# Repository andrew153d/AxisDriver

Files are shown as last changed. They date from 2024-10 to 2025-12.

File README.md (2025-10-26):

# AxisDriver Project

## Overview
The AxisDriver project is a comprehensive solution for controlling motorized devices, designed for robotics and automation applications. It integrates firmware, software, and hardware components to provide a robust and flexible platform for motor control and peripheral management.

## Directory Structure
- `firmware/`: Firmware source code, libraries, and PlatformIO configuration.
- `examples/Python/`: Python scripts for hardware interfacing and control.
- `hardware/`: KiCad files for PCB designs, including Ethernet HATs and mainboards.
- `test/`: Unit tests for hardware components.
- `scripts/`: Utility scripts for generating interfaces and managing configurations.

## Getting Started

### Building the Firmware
1. Navigate to the `firmware/` directory.
2. Build the firmware using PlatformIO:
   ```bash
   platformio run
   ```

### Running Python Scripts
- There are a few python scripts that can control motors over ethernet or USB
1. Navigate to the `examples/Python/` directory.
2. Run the desired script using Python:
   ```bash
   python3 <script_name>.py
   ```

### Ethernet Debugging
- If DEBUG_UDP is defined, run the following in a linux terminal to see messages
```
nc -u -lk 35461
```

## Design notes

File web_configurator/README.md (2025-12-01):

# Axis Driver Web Configurator

A retro computing-themed web interface for configuring and controlling the Axis Driver motor control system.

## 🚀 Quick Start

### Method 1: Use the startup script (Recommended)
```bash
cd web_configurator
./start_server.sh
```

### Method 2: Run Python server directly
```bash
cd web_configurator
python3 serve.py
```

### Method 3: Use any HTTP server
```bash
cd web_configurator
# Python built-in server
python3 -m http.server 8000

# Or Node.js if you have it
npx http-server -p 8000

# Or PHP if you have it
php -S localhost:8000
```

## 🌐 Accessing the Interface

1. Start the server using one of the methods above
2. Open your web browser to: **http://localhost:8000**
3. Connect your Axis Driver via USB
4. Click **[ESTABLISH LINK]** to connect

## ⚡ Requirements

- **Browser**: Chrome 89+ or Edge 89+ (Web Serial API support)
- **Connection**: USB cable to Axis Driver
- **Server**: Python 3 (or any HTTP server)

## 🔧 Features

- **Device Connection**: Serial communication with Axis Driver
- **System Configuration**: Firmware version, I2C, Ethernet settings
- **LED Control**: RGB color and animation control
- **Home Calibration**: Motor homing and calibration
- **Motor Control**: Position, velocity, and path control

## 🎨 Interface

The interface features a retro computing terminal aesthetic with:
- Green-on-black terminal color scheme
- CRT monitor effects (scan lines, flicker)
- Command-line style controls
- Real-time status monitoring
- Monospace terminal font

## 🔐 Security Notes

- The Web Serial API requires either HTTPS or localhost
- Make sure you trust the device you're connecting to
- Only connect genuine Axis Driver devices

## 🐛 Troubleshooting

### "Web Serial API not supported"
- Use Chrome 89+ or Edge 89+
- Ensure you're accessing via HTTP/HTTPS (not file://)

### "HTTPS Required"
- Use localhost instead of file:// protocol
- Serve the files via HTTP server (see instructions above)

### "No Port Selected" 
- Make sure Axis Driver is connected via USB
- Check that device drivers are installed
- Try a different USB cable/port

### "Port Busy"
- Close other applications that might be using the serial port
- Disconnect and reconnect the device
- Refresh the browser page

## 📁 Files

- `index.html` - Main interface
- `style.css` - Retro terminal styling
- `script.js` - Connection and control logic
- `AxisProtocol.js` - Protocol implementation
- `serve.py` - Python HTTP server
- `start_server.sh` - Quick start script

## 🎯 Usage

1. **Connect**: Click [ESTABLISH LINK] to connect via USB
2. **Configure**: Set device parameters (I2C, Ethernet, etc.)
3. **Control**: Use motor control commands
4. **Monitor**: View real-time status and feedback
5. **Disconnect**: Click [DISCONNECT] when done

The interface provides full control over the Axis Driver's configuration and motor control capabilities in an immersive retro computing environment.

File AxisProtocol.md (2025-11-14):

# Axis Driver Protocol Documentation

This document describes the communication protocol for the Axis Driver firmware (Version 1.0.0.0).

## Protocol Overview

The protocol uses a structured message format with a header, body, and footer. All messages are packed structures without padding.

### Message Structure

All messages follow this basic structure:
- **Header** (4 bytes): Message type (2 bytes) + Body size (2 bytes)
- **Body** (variable): Message-specific data
- **Footer** (2 bytes): Checksum

### Data Types

- `uint8_t`: 1 byte unsigned integer
- `int8_t`: 1 byte signed integer
- `uint16_t`: 2 bytes unsigned integer
- `uint32_t`: 4 bytes unsigned integer
- `int32_t`: 4 bytes signed integer
- `double`: 8 bytes floating point

## Message Types

### 0x0100 - ACK (AckId)

**Description**: Acknowledgment message for successful command reception and execution.

| Byte Offset | Size | Field | Description |
| --- | ---- | --- | --- |
| 0-1 | 2 | message_type | 0x0100 |
| 2-3 | 2 | body_size | 3 |
| 4-5 | 2 | ack_message_type | Message type being acknowledged |
| 6 | 1 | status | Status code (0=SUCCESS, 1=ERROR, 2=INVALID_COMMAND) |
| 7-8 | 2 | checksum | Message checksum |

**Status Codes:**
- 0x0: SUCCESS - Command executed successfully
- 0x1: ERROR - Command failed during execution
- 0x2: INVALID_COMMAND - Unknown or malformed command

### 0x0101 - Get Version (GetVersionId)

**Description**: Request firmware version information.

| Byte Offset | Size | Field | Description |
| --- | ---- | --- | --- |
| 0-1 | 2 | message_type | 0x0101 |
| 2-3 | 2 | body_size | 4 |
| 4-7 | 4 | version | Firmware version as uint32_t |
| 8-9 | 2 | checksum | Message checksum |

### 0x0102 - Set I2C Address (SetI2CAddressId)

**Description**: Set the I2C address for the device.

| Byte Offset | Size | Field | Description |
| --- | ---- | --- | --- |
| 0-1 | 2 | message_type | 0x0102 |
| 2-3 | 2 | body_size | 1 |
| 4 | 1 | address | I2C address (0-127) |
| 5-6 | 2 | checksum | Message checksum |

### 0x0103 - Get I2C Address (GetI2CAddressId)

**Description**: Request current I2C address.

| Byte Offset | Size | Field | Description |
| --- | ---- | --- | --- |
| 0-1 | 2 | message_type | 0x0103 |
| 2-3 | 2 | body_size | 1 |
| 4 | 1 | address | Current I2C address |
| 5-6 | 2 | checksum | Message checksum |

### 0x0104 - Set Ethernet Address (SetEthernetAddressId)

**Description**: Set the Ethernet IP address for the device.

| Byte Offset | Size | Field | Description |
| --- | ---- | --- | --- |
| 0-1 | 2 | message_type | 0x0104 |
| 2-3 | 2 | body_size | 4 |
| 4-7 | 4 | ip_address | IP address as uint32_t |
| 8-9 | 2 | checksum | Message checksum |

### 0x0105 - Get Ethernet Address (GetEthernetAddressId)

**Description**: Request current Ethernet IP address.

| Byte Offset | Size | Field | Description |
| --- | ---- | --- | --- |
| 0-1 | 2 | message_type | 0x0105 |
| 2-3 | 2 | body_size | 4 |
| 4-7 | 4 | ip_address | Current IP address as uint32_t |
| 8-9 | 2 | checksum | Message checksum |

### 0x0106 - Set Ethernet Port (SetEthernetPortId)

**Description**: Set the Ethernet port number for the device.

| Byte Offset | Size | Field | Description |
| --- | ---- | --- | --- |
| 0-1 | 2 | message_type | 0x0106 |
| 2-3 | 2 | body_size | 4 |
| 4-7 | 4 | port | Port number as uint32_t |
| 8-9 | 2 | checksum | Message checksum |

### 0x0107 - Get Ethernet Port (GetEthernetPortId)

**Description**: Request current Ethernet port number.

| Byte Offset | Size | Field | Description |
| --- | ---- | --- | --- |
| 0-1 | 2 | message_type | 0x0107 |
| 2-3 | 2 | body_size | 4 |
| 4-7 | 4 | port | Current port number as uint32_t |
| 8-9 | 2 | checksum | Message checksum |

### 0x0108 - Get MAC Address (GetMacAddressId)

**Description**: Request device MAC address.

| Byte Offset | Size | Field | Description |
| --- | ---- | --- | --- |
| 0-1 | 2 | message_type | 0x0108 |
| 2-3 | 2 | body_size | 6 |
| 4-9 | 6 | mac_address  | MAC address bytes |
| 10-11 | 2 | checksum | Message checksum  |

### 0x0109 - Save Configuration (SaveConfigurationId)

**Description**: Save current configuration to non-volatile memory.

| Byte Offset | Size | Field | Description |
| --- | ---- | --- | --- |
| 0-1 | 2 | message_type | 0x0109 |
| 2-3 | 2 | body_size | 1 |
| 4 | 1 | save_flag | 1 to save, 0 for no action |
| 5-6 | 2 | checksum | Message checksum |

### 0x0200 - Set LED Color (SetLedColorId)

**Description**: Set the LED color (RGB values).

| Byte Offset | Size | Field | Description |
| --- | ---- | --- | --- |
| 0-1 | 2 | message_type | 0x0200 |
| 2-3 | 2 | body_size | 3 |
| 4 | 1 | red | Red component (0-255) |
| 5 | 1 | green | Green component (0-255) |
| 6 | 1 | blue | Blue component (0-255)  |
| 7-8 | 2 | checksum | Message checksum |

### 0x0201 - Get LED Color (GetLedColorId)

**Description**: Request current LED color.

| Byte Offset | Size | Field | Description |
| --- | ---- | --- | --- |
| 0-1 | 2 | message_type | 0x0201 |
| 2-3 | 2 | body_size | 3 |
| 4 | 1 | red | Current red component |
| 5 | 1 | green | Current green component |
| 6 | 1 | blue | Current blue component  |
| 7-8 | 2 | checksum | Message checksum |

### 0x0202 - Add Led Step (AddLedStepId)

**Description**: Add a timed LED step with a duration and color. Useful for sequencing LED patterns step-by-step.

| Byte Offset | Size | Field | Description |
| --- | ---- | --- | --- |
| 0-1 | 2 | message_type | 0x0202 |
| 2-3 | 2 | body_size | 7 |
| 4-7 | 4 | time_ms | Duration/time in milliseconds (uint32_t) |
| 8 | 1 | red | Red component (0-255) |
| 9 | 1 | green | Green component (0-255) |
| 10 | 1 | blue | Blue component (0-255) |
| 11-12 | 2 | checksum | Message checksum |

### 0x0300 - Set Home Direction (SetHomeDirectionId)

**Description**: Set the homing direction for the motor.

| Byte Offset | Size | Field | Description |
| --- | ---- | --- | --- |
| 0-1 | 2 | message_type | 0x0300 |
| 2-3 | 2 | body_size | 1 |
| 4 | 1 | direction | Home direction (0=CLOCKWISE, 1=COUNTERCLOCKWISE) |
| 5-6 | 2 | checksum | Message checksum |

### 0x0301 - Get Home Direction (GetHomeDirectionId)

**Description**: Request current homing direction.

| Byte Offset | Size | Field | Description |
| --- | ---- | --- | --- |
| 0-1 | 2 | message_type | 0x0301 |
| 2-3 | 2 | body_size | 1 |
| 4 | 1 | direction | Current home direction |
| 5-6 | 2 | checksum | Message checksum |

### 0x0302 - Set Home Threshold (SetHomeThresholdId)

**Description**: Set the threshold value for homing detection.

| Byte Offset | Size | Field | Description |
| --- | ---- | --- | --- |
| 0-1 | 2 | message_type | 0x0302 |
| 2-3 | 2 | body_size | 4 |
| 4-7 | 4 | threshold | Home detection threshold as uint32_t |
| 8-9 | 2 | checksum | Message checksum |

### 0x0303 - Get Home Threshold (GetHomeThresholdId)

**Description**: Request current home threshold value.

| Byte Offset | Size | Field | Description |
| --- | ---- | --- | --- |
| 0-1 | 2 | message_type | 0x0303 |
| 2-3 | 2 | body_size | 4 |
| 4-7 | 4 | threshold | Current home threshold |
| 8-9 | 2 | checksum | Message checksum |

### 0x0304 - Set Home Speed (SetHomeSpeedId)

**Description**: Set the speed for homing operations.

| Byte Offset | Size | Field | Description |
| --- | ---- | --- | --- |
| 0-1 | 2 | message_type | 0x0304 |
| 2-3 | 2 | body_size | 4 |
| 4-7 | 4 | speed | Home speed as uint32_t |
| 8-9 | 2 | checksum | Message checksum |

### 0x0305 - Get Home Speed (GetHomeSpeedId)

**Description**: Request current homing speed.

| Byte Offset | Size | Field | Description |
| --- | ---- | --- | --- |
| 0-1 | 2 | message_type | 0x0305 |
| 2-3 | 2 | body_size | 4 |
| 4-7 | 4 | speed | Current home speed |
| 8-9 | 2 | checksum | Message checksum |

### 0x0306 - Get Homed State (GetHomedStateId)

**Description**: Request whether the motor has been homed.

| Byte Offset | Size | Field | Description |
| --- | ---- | --- | --- |
| 0-1 | 2 | message_type | 0x0306 |
| 2-3 | 2 | body_size | 1 |
| 4 | 1 | homed | 1 if homed, 0 if not homed |
| 5-6 | 2 | checksum | Message checksum |

### 0x0400 - Home (HomeId)

**Description**: Initiate homing sequence.

| Byte Offset | Size | Field | Description |
| --- | ---- | --- | --- |
| 0-1 | 2 | message_type | 0x0400 |
| 2-3 | 2 | body_size | 4 |
| 4-7 | 4 | home_command | Home command value |
| 8-9 | 2 | checksum | Message checksum |

### 0x0307 - Set Motor State (SetMotorStateId)

**Description**: Set the motor control state/mode.

| Byte Offset | Size | Field | Description |
| --- | ---- | --- | --- |
| 0-1 | 2 | message_type | 0x0307 |
| 2-3 | 2 | body_size | 1 |
| 4 | 1 | motor_state  | Motor state (see MotorStates enum) |
| 5-6 | 2 | checksum | Message checksum |

**Motor States:**
- 0x0: OFF
- 0x1: POSITION
- 0x2: VELOCITY
- 0x3: VELOCITY_STEP
- 0x4: IDLE_ON
- 0x5: HOME

### 0x0308 - Get Motor State (GetMotorStateId)

**Description**: Request current motor state.

| Byte Offset | Size | Field | Description |
| --- | ---- | --- | --- |
| 0-1 | 2 | message_type | 0x0308 |
| 2-3 | 2 | body_size | 1 |
| 4 | 1 | motor_state  | Current motor state |
| 5-6 | 2 | checksum | Message checksum |

### 0x0309 - Set Motor Brake (SetMotorBrakeId)

**Description**: Set the motor braking mode.

| Byte Offset | Size | Field | Description |
| --- | ---- | --- | --- |
| 0-1 | 2 | message_type | 0x0309 |
| 2-3 | 2 | body_size | 1 |
| 4 | 1 | brake_mode | Brake mode (see MotorBrake enum) |
| 5-6 | 2 | checksum | Message checksum |

**Motor Brake Modes:**
- 0x0: NORMAL
- 0x1: FREEWHEELING
- 0x2: STRONG_BRAKING
- 0x3: BRAKING

### 0x030A - Get Motor Brake (GetMotorBrakeId)

**Description**: Request current motor brake mode.

| Byte Offset | Size | Field | Description |
| --- | ---- | --- | --- |
| 0-1 | 2 | message_type | 0x030A |
| 2-3 | 2 | body_size | 1 |
| 4 | 1 | brake_mode | Current brake mode |
| 5-6 | 2 | checksum | Message checksum |

### 0x030B - Set Max Speed (SetMaxSpeedId)

**Description**: Set the maximum motor speed.

| Byte Offset | Size | Field | Description |
| --- | ---- | --- | --- |
| 0-1 | 2 | message_type | 0x030B |
| 2-3 | 2 | body_size | 4 |
| 4-7 | 4 | max_speed | Maximum speed as uint32_t |
| 8-9 | 2 | checksum | Message checksum |

### 0x030C - Get Max Speed (GetMaxSpeedId)

**Description**: Request current maximum speed setting.

| Byte Offset | Size | Field | Description |
| --- | ---- | --- | --- |
| 0-1 | 2 | message_type | 0x030C |
| 2-3 | 2 | body_size | 4 |
| 4-7 | 4 | max_speed | Current maximum speed |
| 8-9 | 2 | checksum | Message checksum |

### 0x030D - Set Acceleration (SetAccelerationId)

**Description**: Set the motor acceleration value.

| Byte Offset | Size | Field | Description |
| --- | ---- | --- | --- |
| 0-1 | 2 | message_type | 0x030D |
| 2-3 | 2 | body_size | 4 |
| 4-7 | 4 | acceleration | Acceleration as uint32_t |
| 8-9 | 2 | checksum | Message checksum |

### 0x030E - Get Acceleration (GetAccelerationId)

**Description**: Request current acceleration setting.

| Byte Offset | Size | Field | Description |
| --- | ---- | --- | --- |
| 0-1 | 2 | message_type | 0x030E |
| 2-3 | 2 | body_size | 4 |
| 4-7 | 4 | acceleration | Current acceleration |
| 8-9 | 2 | checksum | Message checksum |

### 0x030F - Set Current Position (SetCurrentPositionId)

**Description**: Set the current position (zero/reference the position).

| Byte Offset | Size | Field | Description |
| --- | ---- | --- | --- |
| 0-1 | 2 | message_type | 0x030F |
| 2-3 | 2 | body_size | 8 |
| 4-11 | 8 | position | Position in degrees as double |
| 12-13 | 2 | checksum | Message checksum |

### 0x0310 - Get Current Position (GetCurrentPositionId)

**Description**: Request current motor position.

| Byte Offset | Size | Field | Description |
| --- | ---- | --- | --- |
| 0-1 | 2 | message_type | 0x0310 |
| 2-3 | 2 | body_size | 8 |
| 4-11 | 8 | position | Current position in degrees as double |
| 12-13 | 2 | checksum | Message checksum |

### 0x0311 - Set Target Position (SetTargetPositionId)

**Description**: Set the target position for position control mode.

| Byte Offset | Size | Field | Description |
| --- | ---- | --- | --- |
| 0-1 | 2 | message_type | 0x0311 |
| 2-3 | 2 | body_size | 8 |
| 4-11 | 8 | position | Target position in degrees as double |
| 12-13 | 2 | checksum | Message checksum |

### 0x0312 - Get Target Position (GetTargetPositionId)

**Description**: Request current target position.

| Byte Offset | Size | Field | Description |
| --- | ---- | --- | --- |
| 0-1 | 2 | message_type | 0x0312 |
| 2-3 | 2 | body_size | 8 |
| 4-11 | 8 | position | Current target position in degrees as double |
| 12-13 | 2 | checksum | Message checksum |

### 0x0401 - Set Relative Target Position (SetRelativeTargetPositionId)

**Description**: Set a target position relative to the current position.

| Byte Offset | Size | Field | Description |
| --- | ---- | --- | --- |
| 0-1 | 2 | message_type | 0x0401 |
| 2-3 | 2 | body_size | 8 |
| 4-11 | 8 | relative_position | Relative position in degrees as double |
| 12-13 | 2 | checksum | Message checksum |

### 0x0313 - Set Velocity (SetVelocityId)

**Description**: Set the motor velocity for velocity control mode.

| Byte Offset | Size | Field | Description |
| --- | ---- | --- | --- |
| 0-1 | 2 | message_type | 0x0313 |
| 2-3 | 2 | body_size | 8 |
| 4-11 | 8 | velocity | Velocity in degrees/second as double |
| 12-13 | 2 | checksum | Message checksum |

### 0x0314 - Get Velocity (GetVelocityId)

**Description**: Request current motor velocity.

| Byte Offset | Size | Field | Description |
| --- | ---- | --- | --- |
| 0-1 | 2 | message_type | 0x0314 |
| 2-3 | 2 | body_size | 8 |
| 4-11 | 8 | velocity | Current velocity in degrees/second as double |
| 12-13 | 2 | checksum | Message checksum |

### 0x0402 - Set Velocity and Steps (SetVelocityAndStepsId)

**Description**: Set velocity and number of steps with position mode.

| Byte Offset | Size | Field | Description |
| --- | ---- | --- | --- |
| 0-1 | 2 | message_type  | 0x0402 |
| 2-3 | 2 | body_size | 9 |
| 4-7 | 4 | velocity | Velocity as int32_t |
| 8-11 | 4 | steps | Number of steps as int32_t |
| 12 | 1 | position_mode | Position mode (0=ABSOLUTE, 1=RELATIVE) |
| 13-14 | 2 | checksum | Message checksum |

### 0x0403 - Start Path (StartPathId)

**Description**: Start executing a predefined motion path.

| Byte Offset | Size | Field | Description |
| --- | ---- | --- | --- |
| 0-1 | 2 | message_type | 0x0403 |
| 2-3 | 2 | body_size | 1 |
| 4 | 1 | path_id | Path identifier to execute |
| 5-6 | 2 | checksum | Message checksum |

## Checksum Calculation

The checksum is calculated as a 16-bit CRC or sum of all bytes in the header and body. The specific algorithm should be documented based on the firmware implementation.

## Error Handling

Messages with invalid checksums, unknown message types, or incorrect body sizes should be ignored or responded to with an error message.

## LLM Prompt for File Generation

Use the following prompt to instruct an LLM to generate implementation files based on this protocol documentation:

"Based on the Axis Driver Protocol Documentation provided in AxisProtocol.md, update firmware/include/AxisMessages.h, examples/Python/AxisProtocol.py, and web_configurator/AxisProtocol.js that implement the message structures, parsing, and serialization for the communication protocol. Include:

- Definitions for all message types with their exact byte offsets, sizes, and field names.
- Length definitions for each message type
- Enums for status codes, motor states, brake modes, etc.
- Update any existing functionality with any changes to the protocol

Ensure the generated code is compatible with the data types specified (uint8_t, int32_t, double, etc.) and follows the packed structure without padding. Provide complete, runnable code snippets or files that can be integrated into firmware or client applications."

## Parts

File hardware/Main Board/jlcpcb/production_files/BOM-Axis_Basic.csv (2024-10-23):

Comment | Designator | Footprint | LCSC
100n | C12,C15 | C_0402_1005Metric | C1525
10k | R11,R12,R6,R9 | R_0402_1005Metric | C25744
5.1k | R2,R3 | R_0402_1005Metric | C25905
1M | R1 | R_0402_1005Metric | C26083
TMC2209-LA | U4 | QFN-28-1EP_5x5mm_P0.5mm_EP3.35x3.35mm_ThermalVias | C465949
UA78M33CDCYR | U2 | SOT-223-3_TabPin2 | C49036
1uf | C6 | C_0402_1005Metric
22pF | C3 | C_0402_1005Metric
10k | R10 | R_0402_1005Metric
0.33u | C1 | C_0402_1005Metric
ESD5Z3V3 | D4 | D_SOD-523
ATSAMD51J19A-AUT | U3 | TQFP-64_10x10mm_P0.5mm
JST_SH | J4 | JST_SH_SM04B-SRSS-TB_1x04-1MP_P1.00mm_Horizontal
ESD5Z3V3 | D5 | D_SOD-523
10uf | C5 | C_0805_2012Metric
1-84952-4 | J6 | TE_1-84952-4_1x14-1MP_P1.0mm_Horizontal
MountingHole | H1 | MountingHole_3.2mm_M3_ISO14580_Pad
1k | R15 | R_0402_1005Metric
100k | R4 | R_0402_1005Metric
1uf | C9 | C_0402_1005Metric
0.1u | C4 | C_0402_1005Metric
10k | R5 | R_0402_1005Metric
1uf | C8 | C_0402_1005Metric
JST_PH | J2 | JST_PH_S4B-PH-K_1x04_P2.00mm_Horizontal
ESD5Z3V3 | D3 | D_SOD-523
32.768 | Y1 | Crystal_SMD_3215-2Pin_3.2x1.5mm
10k | R8 | R_0402_1005Metric
MountingHole | H4 | MountingHole_3.2mm_M3_ISO14580_Pad
1uf | C11 | C_0402_1005Metric
100n | C17 | C_0402_1005Metric
XZMDK54W-1 | D6 | LED_0603_1608Metric
100n | C16 | C_0402_1005Metric
ESD5Z3V3 | D7 | D_SOD-523
1uf | C10 | C_0402_1005Metric
PMEG3020EJ | D1 | D_SOD-323F
RKB2SJK | SW1 | button_RKB2SJK250SMTR LFS
24AA02E-OT | U5 | SOT-23-5
22u | C18 | C_0805_2012Metric
2.2u | C14 | C_0402_1005Metric
RKB2SJK | SW2 | button_RKB2SJK250SMTR LFS
MMSZ5254B | D2 | D_SOD-123
22pF | C2 | C_0402_1005Metric
10uf | C7 | C_0805_2012Metric
10k | R7 | R_0402_1005Metric
MountingHole | H3 | MountingHole_3.2mm_M3_ISO14580_Pad
22n | C13 | C_0402_1005Metric
300 | R13 | R_0402_1005Metric
10k | R14 | R_0402_1005Metric
JST_SH | J3 | JST_SH_SM04B-SRSS-TB_1x04-1MP_P1.00mm_Horizontal
S2B-PH-K-S | J5 | JST_PH_S2B-PH-K_1x02_P2.00mm_Horizontal
MountingHole | H2 | MountingHole_3.2mm_M3_ISO14580_Pad
USB4105-GF-A | J1 | USB_C_Receptacle_GCT_USB4105-xx-A_16P_TopMnt_Horizontal
TLV493D | U1 | SOT-23-6
120m | R21 | R_1206_3216Metric
100k | R16 | R_0402_1005Metric
1k | R19 | R_0402_1005Metric
10uh | L1 | L_0603_1608Metric
47u | C21 | CP_Elec_6.3x5.4
XZMDK54W-1 | D9 | LED_0603_1608Metric
22u | C20 | C_0805_2012Metric
100n | C19 | C_0402_1005Metric
1k | R18 | R_0402_1005Metric
10k | R17 | R_0402_1005Metric
WS2812B | D10 | LED_WS2812B_PLCC4_5.0x5.0mm_P3.2mm
120m | R20 | R_1206_3216Metric
ESD5Z3V3 | D8 | D_SOD-523
TestPoint | GND1 | TestPoint_Pad_D2.0mm
TestPoint | CLK1 | TestPoint_Pad_D2.0mm
TestPoint | RST1 | TestPoint_Pad_D2.0mm
TestPoint | SIO1 | TestPoint_Pad_D2.0mm

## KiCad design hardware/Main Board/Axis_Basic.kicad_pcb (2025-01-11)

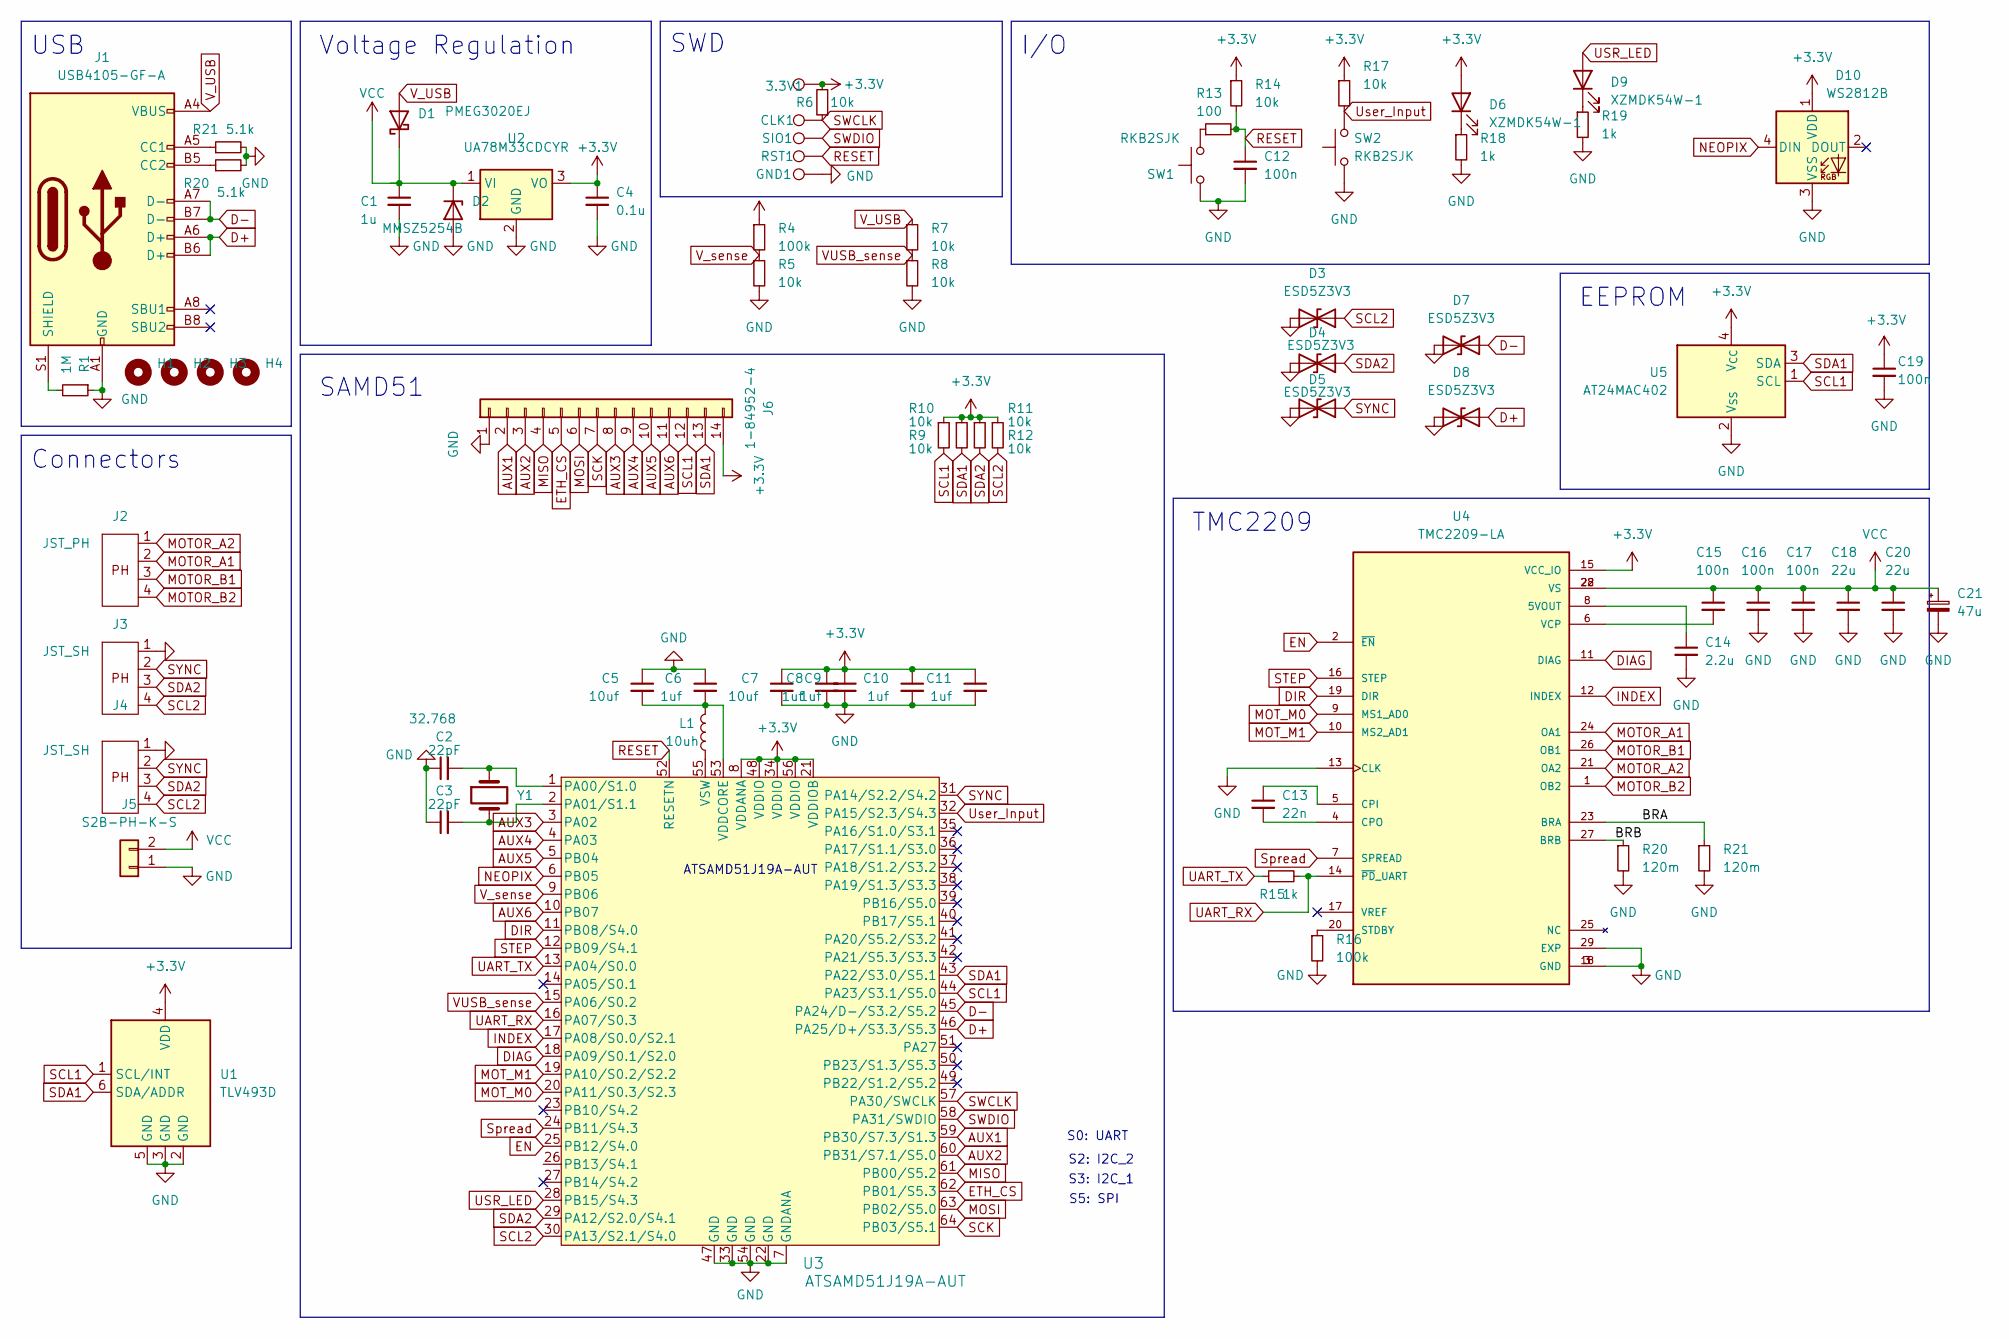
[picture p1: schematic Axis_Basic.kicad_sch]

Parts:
3.3V1: TestPoint; TestPoint_Pad_D2.0mm
C1: 1u; C_0402_1005Metric
C2, C3: 22pF; C_0402_1005Metric
C4: 0.1u; C_0402_1005Metric
C5, C7: 10uf; C_0805_2012Metric
C6, C8, C9, C10, C11: 1uf; C_0402_1005Metric
C12, C15, C16, C17, C19: 100n; C_0402_1005Metric
C13: 22n; C_0402_1005Metric
C14: 2.2u; C_0402_1005Metric
C18, C20: 22u; C_0805_2012Metric
C21: 47u; CP_Elec_6.3x5.4
CLK1: TestPoint; TestPoint_Pad_D2.0mm
D1: PMEG3020EJ; D_SOD-323F
D2: MMSZ5254B; D_SOD-123
D3, D4, D5, D7, D8: ESD5Z3V3; D_SOD-523
D6, D9: XZMDK54W-1; LED_0603_1608Metric
D10: WS2812B; LED_WS2812B_PLCC4_5.0x5.0mm_P3.2mm
GND1: TestPoint; TestPoint_Pad_D2.0mm
H1, H2, H3, H4: MountingHole; MountingHole_3.2mm_M3_ISO14580_Pad
J1: USB4105-GF-A; USB_C_Receptacle_GCT_USB4105-xx-A_16P_TopMnt_Horizontal
J2: JST_PH; JST_PH_S4B-PH-K_1x04_P2.00mm_Horizontal
J3, J4: JST_SH; JST_SH_SM04B-SRSS-TB_1x04-1MP_P1.00mm_Horizontal
J5: S2B-PH-K-S; JST_PH_S2B-PH-K_1x02_P2.00mm_Horizontal
J6: 1-84952-4; TE_1-84952-4_1x14-1MP_P1.0mm_Horizontal
L1: 10uh; L_0603_1608Metric
R1: 1M; R_0402_1005Metric
R4, R16: 100k; R_0402_1005Metric
R5, R6, R7, R8, R9, R10, R11, R12, R14, R17: 10k; R_0402_1005Metric
R13: 100; R_0402_1005Metric
R15, R18, R19: 1k; R_0402_1005Metric
R20, R21: 5.1k; R_0402_1005Metric
RST1: TestPoint; TestPoint_Pad_D2.0mm
SIO1: TestPoint; TestPoint_Pad_D2.0mm
SW1, SW2: RKB2SJK; button_RKB2SJK250SMTR LFS
U1: TLV493D; SOT-23-6
U2: UA78M33CDCYR; SOT-223-3_TabPin2
U3: ATSAMD51J19A-AUT; TQFP-64_10x10mm_P0.5mm
U4: TMC2209-LA; QFN-28-1EP_5x5mm_P0.5mm_EP3.35x3.35mm_ThermalVias; PARTREV 1.08
U5: AT24MAC402; SOT-23-5
Y1: 32.768; Crystal_SMD_3215-2Pin_3.2x1.5mm

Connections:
+3.3V: 3.3V1.1, C4.1, C7.1, C8.1, C9.1, C10.1, C11.1, C19.1, D6.2 (A), D10.1 (VDD), J6.14, R6.2, R9.1, R10.1, R11.1, R12.1, R14.1, R17.1, U1.4 (VDD), U2.3 (VO), U3.8 (VDDANA), U3.21 (VDDIOB), U3.34 (VDDIO), U3.48 (VDDIO), U3.56 (VDDIO), U4.15 (VCC_IO), U5.4 (V_{CC})
AUX1: J6.2, U3.59 (PB30/S7.3/S1.3)
AUX2: J6.3, U3.60 (PB31/S7.1/S5.0)
AUX3: J6.8, U3.3 (PA02)
AUX4: J6.9, U3.4 (PA03)
AUX5: J6.10, U3.5 (PB04)
AUX6: J6.11, U3.10 (PB07)
D+: D8.1 (A1), J1.A6 (D+), J1.B6 (D+), U3.46 (PA25/D+/S3.3/S5.3)
D-: D7.1 (A1), J1.A7 (D-), J1.B7 (D-), U3.45 (PA24/D-/S3.2/S5.2)
DIAG: U3.18 (PA09/S0.1/S2.0), U4.11 (DIAG)
DIR: U3.11 (PB08/S4.0), U4.19 (DIR)
EN: U3.25 (PB12/S4.0), U4.2 (~EN)
ETH_CS: J6.5, U3.62 (PB01/S5.3)
GND: C1.2, C2.1, C3.1, C4.2, C5.1, C6.1, C7.2, C8.2, C9.2, C10.2, C11.2, C12.2, C14.2, C16.2, C17.2, C18.2, C19.2, C20.2, C21.2, D2.2 (A), D3.2 (A2), D4.2 (A2), D5.2 (A2), D7.2 (A2), D8.2 (A2), D10.3 (VSS), GND1.1, J1.A1 (GND), J1.A12 (GND), J1.B1 (GND), J1.B12 (GND), J3.1, J4.1, J5.1, J6.1, R1.1, R5.2, R8.2, R16.2, R18.2, R19.2, R20.2, R21.2, SW1.1, SW2.1, U1.2 (GND), U1.3 (GND), U1.5 (GND), U2.2 (GND), U3.7 (GNDANA), U3.22 (GND), U3.33 (GND), U3.47 (GND), U3.54 (GND), U4.3 (GND), U4.13 (CLK), U4.18 (GND), U4.29 (EXP), U5.2 (V_{SS}); also elsewhere on the board
INDEX: U3.17 (PA08/S0.0/S2.1), U4.12 (INDEX)
MISO: J6.4, U3.61 (PB00/S5.2)
MOSI: J6.6, U3.63 (PB02/S5.0)
MOTOR_A1: J2.2, U4.24 (OA1)
MOTOR_A2: J2.1, U4.21 (OA2)
MOTOR_B1: J2.3, U4.26 (OB1)
MOTOR_B2: J2.4, U4.1 (OB2)
MOT_M0: U3.20 (PA11/S0.3/S2.3), U4.9 (MS1_AD0)
MOT_M1: U3.19 (PA10/S0.2/S2.2), U4.10 (MS2_AD1)
NEOPIX: D10.4 (DIN), U3.6 (PB05)
unnamed: D6.1 (K), R18.1
unnamed: D9.1 (K), R19.1
unnamed: J1.S1 (SHIELD), R1.2
unnamed: R13.1, SW1.2
unnamed: C2.2, U3.1 (PA00/S1.0), Y1.1
unnamed: C3.2, U3.2 (PA01/S1.1), Y1.2
unnamed: C5.2, C6.2, L1.2, U3.53 (VDDCORE)
unnamed: L1.1, U3.55 (VSW)
unnamed: C14.1, U4.8 (5VOUT)
unnamed: C13.1, U4.5 (CPI)
unnamed: C13.2, U4.4 (CPO)
unnamed: R16.1, U4.20 (STDBY)
unnamed: C15.2, U4.6 (VCP)
RESET: C12.1, R13.2, R14.2, RST1.1, U3.52 (RESETN)
SCK: J6.7, U3.64 (PB03/S5.1)
SCL1: J6.12, R9.2, U1.1 (SCL/INT), U3.44 (PA23/S3.1/S5.0), U5.1 (SCL)
SCL2: D3.1 (A1), J3.4, J4.4, R12.2, U3.30 (PA13/S2.1/S4.0)
SDA1: J6.13, R10.2, U1.6 (SDA/ADDR), U3.43 (PA22/S3.0/S5.1), U5.3 (SDA)
SDA2: D4.1 (A1), J3.3, J4.3, R11.2, U3.29 (PA12/S2.0/S4.1)
STEP: U3.12 (PB09/S4.1), U4.16 (STEP)
SWCLK: CLK1.1, R6.1, U3.57 (PA30/SWCLK)
SWDIO: SIO1.1, U3.58 (PA31/SWDIO)
SYNC: D5.1 (A1), J3.2, J4.2, U3.31 (PA14/S2.2/S4.2)
Spread: U3.24 (PB11/S4.3), U4.7 (SPREAD)
UART_RX: R15.2, U3.16 (PA07/S0.3), U4.14 (~PD_UART)
UART_TX: R15.1, U3.13 (PA04/S0.0)
USR_LED: D9.2 (A), U3.28 (PB15/S4.3)
User_Input: R17.2, SW2.2, U3.32 (PA15/S2.3/S4.3)
VCC: C1.1, C15.1, C16.1, C17.1, C18.1, C20.1, C21.1, D1.1 (K), D2.1 (K), J5.2, R4.1, U2.1 (VI), U4.22 (VS), U4.28 (VS)
VUSB_sense: R7.2, R8.1, U3.15 (PA06/S0.2)
V_USB: D1.2 (A), J1.A4 (VBUS), J1.A9 (VBUS), J1.B4 (VBUS), J1.B9 (VBUS), R7.1
V_sense: R4.2, R5.1, U3.9 (PB06)

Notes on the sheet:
S2: I2C_2
SAMD51
EEPROM
S3: I2C_1
Connectors
TMC2209
I/O
ATSAMD51J19A-AUT
Voltage Regulation
S0: UART
SWD
S5: SPI
USB

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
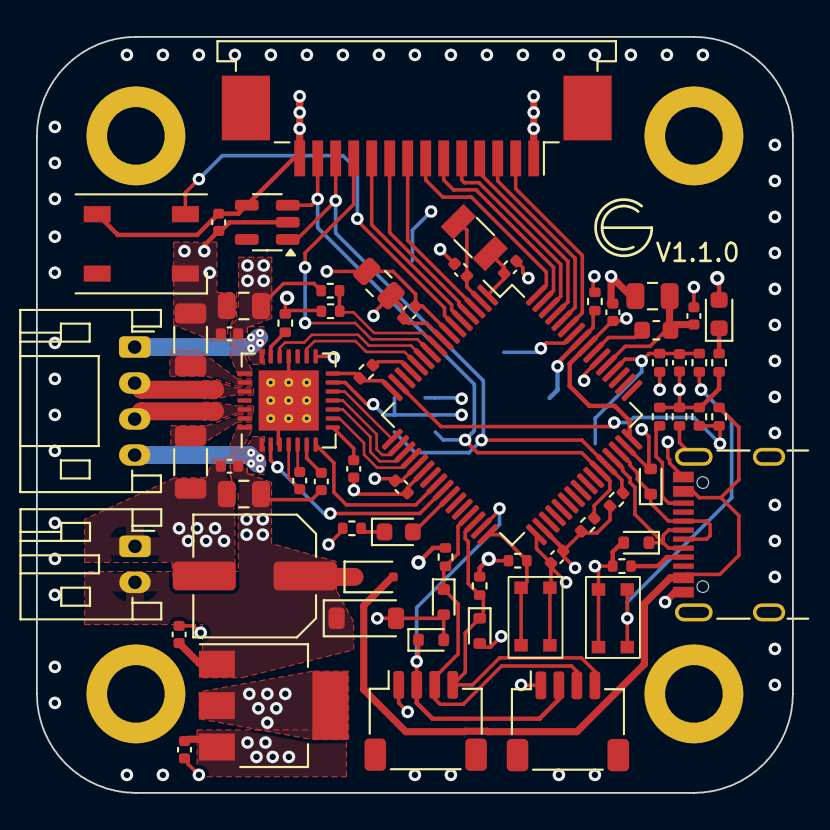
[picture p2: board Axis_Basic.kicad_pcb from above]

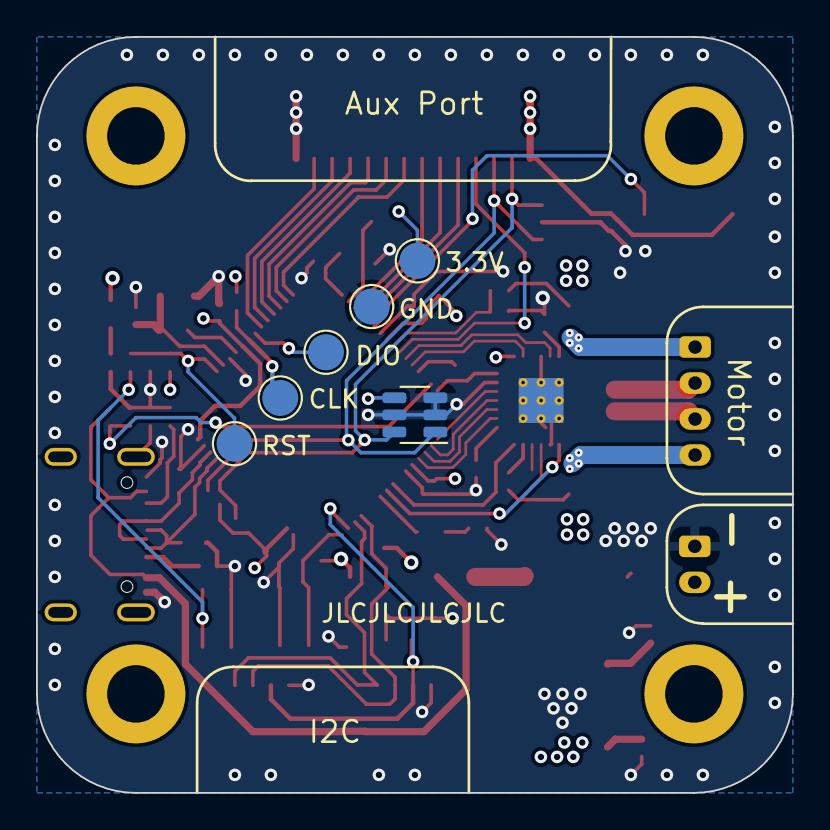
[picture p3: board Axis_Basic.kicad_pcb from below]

Board: 4 copper layers, 42.0 x 42.0 mm, 76 parts (6 on the bottom side), 60 nets.

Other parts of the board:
R2, R3: 5.1k; R_0402_1005Metric

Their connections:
GND: R2.2, R3.2; also elsewhere on the board

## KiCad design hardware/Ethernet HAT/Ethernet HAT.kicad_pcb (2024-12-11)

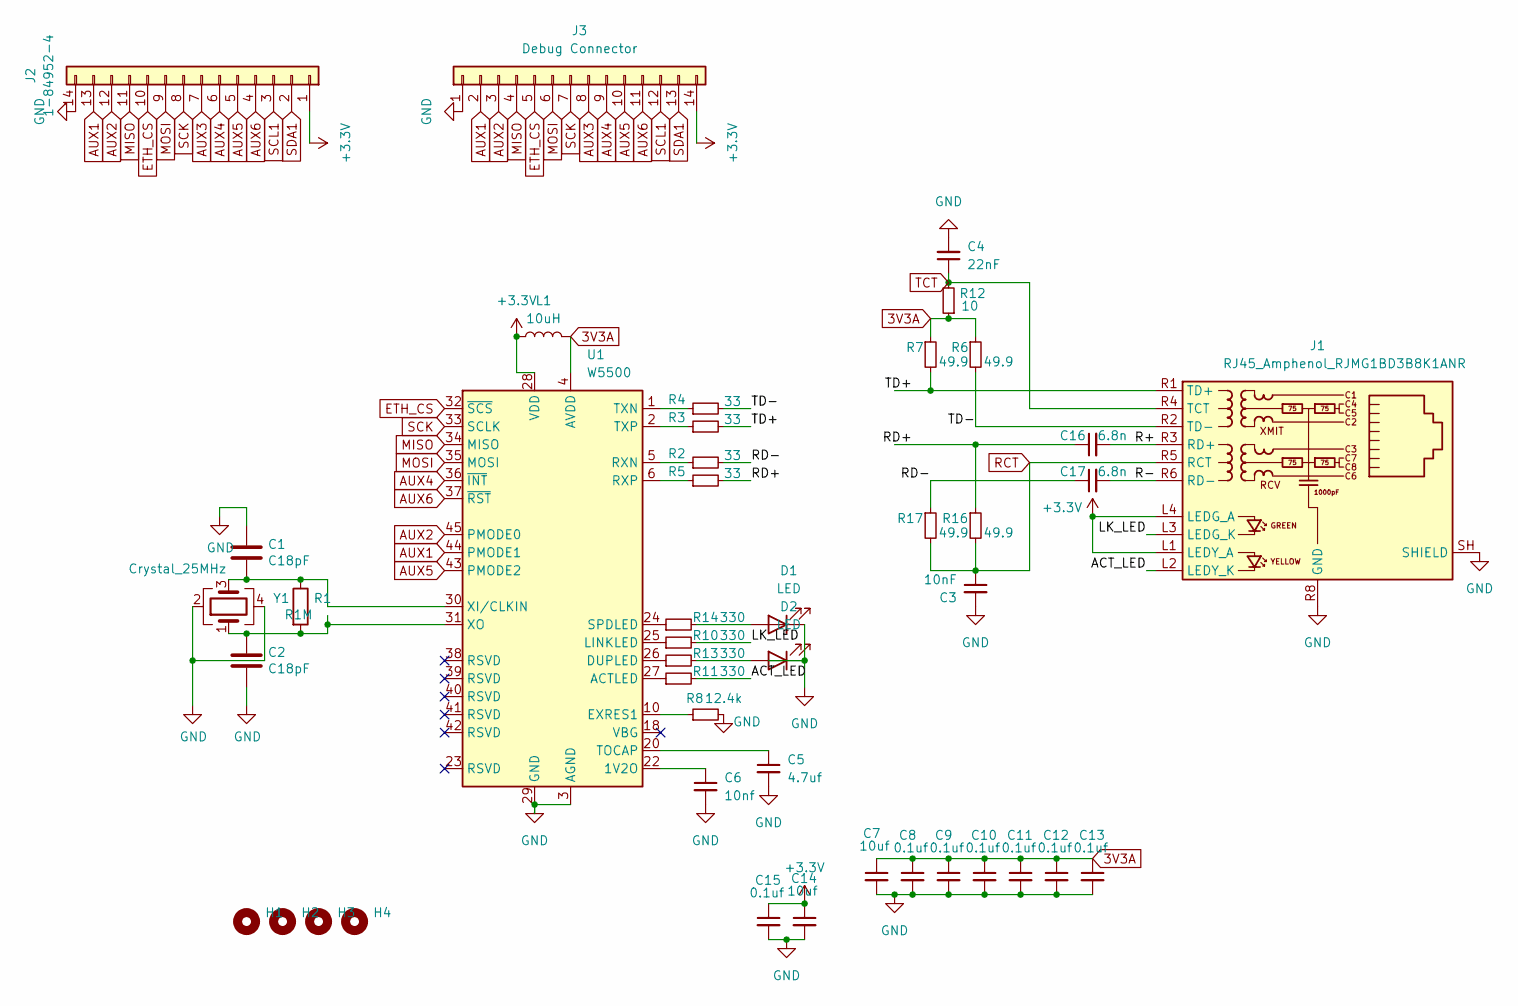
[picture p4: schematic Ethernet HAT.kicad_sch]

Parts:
C1, C2: C18pF; C_0402_1005Metric; LCSC C1549
C3: 10nF; C_0402_1005Metric
C4: 22nF; C_0402_1005Metric
C5: 4.7uf; C_0402_1005Metric
C6: 10nf; C_0402_1005Metric
C7, C14: 10uf; C_0805_2012Metric
C8, C9, C10, C11, C12, C13, C15: 0.1uf; C_0402_1005Metric
C16, C17: 6.8n; C_0402_1005Metric
D1, D2: LED; LED_0603_1608Metric
H1, H2, H3, H4: MountingHole; MountingHole_3.2mm_M3_ISO14580_Pad
J1: RJ45_Amphenol_RJMG1BD3B8K1ANR
J2: 1-84952-4; TE_1-84952-4_1x14-1MP_P1.0mm_Horizontal
J3: Debug Connector; Conn_01x14_Flat2.54
L1: 10uH; L_0603_1608Metric
R1: R1M; R_0402_1005Metric; LCSC C26083
R2, R3, R4, R5: 33; R_0402_1005Metric
R6, R7, R16, R17: 49.9; R_0402_1005Metric
R8: 12.4k; R_0603_1608Metric
R10, R11, R13, R14: 330; R_0402_1005Metric
R12: 10; R_0402_1005Metric
U1: W5500; LQFP-48_7x7mm_P0.5mm
Y1: Crystal_25MHz; Crystal_SMD_3225-4Pin_3.2x2.5mm; LCSC C9006

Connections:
3V3A: C7.1, C8.1, C9.1, C10.1, C11.1, C12.1, C13.1, L1.2, R6.1, R7.1, R12.1, U1.4 (AVDD), U1.8 (AVDD), U1.11 (AVDD), U1.15 (AVDD), U1.17 (AVDD), U1.21 (AVDD)
+3.3V: C14.1, C15.1, J1.L1 (LEDY_A), J1.L4 (LEDG_A), J2.1, J3.14, L1.1, U1.28 (VDD)
/ACT_LED: J1.L2 (LEDY_K), R11.2
/LK_LED: J1.L3 (LEDG_K), R10.2
/R+: C16.2, J1.R3 (RD+)
/R-: C17.2, J1.R6 (RD-)
/RD+: C16.1, R5.2, R16.1
/RD-: C17.1, R2.2, R17.1
/TD+: J1.R1 (TD+), R3.2, R7.2
/TD-: J1.R2 (TD-), R4.2, R6.2
AUX1: J2.13, J3.2, U1.44 (PMODE1)
AUX2: J2.12, J3.3, U1.45 (PMODE0)
AUX3: J2.7, J3.8
AUX4: J2.6, J3.9, U1.36 (~INT)
AUX5: J2.5, J3.10, U1.43 (PMODE2)
AUX6: J2.4, J3.11, U1.37 (~RST)
ETH_CS: J2.10, J3.5, U1.32 (~SCS)
GND: C1.1, C2.2, C3.2, C4.2, C5.2, C6.2, C7.2, C8.2, C9.2, C10.2, C11.2, C12.2, C13.2, C14.2, C15.2, D1.1 (K), D2.1 (K), J1.R8 (GND), J1.SH (SHIELD), J2.14, J3.1, R8.2, U1.3 (AGND), U1.9 (AGND), U1.14 (AGND), U1.16 (AGND), U1.19 (AGND), U1.29 (GND), U1.48 (AGND), Y1.2, Y1.4
MISO: J2.11, J3.4, U1.34 (MISO)
MOSI: J2.9, J3.6, U1.35 (MOSI)
unnamed: D1.2 (A), R14.2
unnamed: D2.2 (A), R13.2
unnamed: C6.1, U1.22 (1V2O)
unnamed: R11.1, U1.27 (ACTLED)
unnamed: R13.1, U1.26 (DUPLED)
unnamed: R8.1, U1.10 (EXRES1)
unnamed: R10.1, U1.25 (LINKLED)
unnamed: R2.1, U1.5 (RXN)
unnamed: R5.1, U1.6 (RXP)
unnamed: R14.1, U1.24 (SPDLED)
unnamed: C5.1, U1.20 (TOCAP)
unnamed: R4.1, U1.1 (TXN)
unnamed: R3.1, U1.2 (TXP)
unnamed: C1.2, R1.1, U1.30 (XI/CLKIN), Y1.3
unnamed: C2.1, R1.2, U1.31 (XO), Y1.1
RCT: C3.1, J1.R5 (RCT), R16.2, R17.2
SCK: J2.8, J3.7, U1.33 (SCLK)
SCL1: J2.3, J3.12
SDA1: J2.2, J3.13
TCT: C4.1, J1.R4 (TCT), R12.2

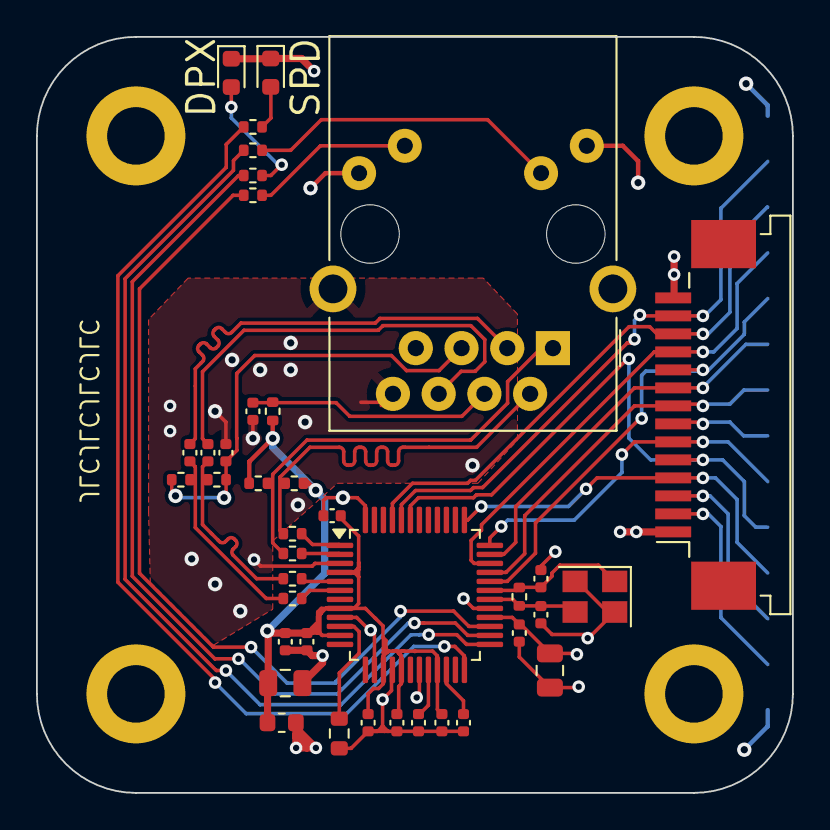
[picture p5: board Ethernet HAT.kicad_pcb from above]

Board: 4 copper layers, 42.0 x 42.0 mm, 44 parts (1 on the bottom side), 40 nets.

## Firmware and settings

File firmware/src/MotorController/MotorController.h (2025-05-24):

#pragma once
#include <Arduino.h>
#include "Task/Task.h"
#include "MotorController/AccelStepper.h"
#include "LedController/LedController.h"
#include "easyTMC2209.h"
#include "wiring_private.h"
#include "pid.h"
#include "AxisMessages.h"
#include "DebugPrinter.h"

#define SERIAL_PORT Serial1
#define R_SENSE 0.12f

#define DEFAULT_HOMING_SPEED 100
#define DEFAULT_HOMING_DIRECTION 1
#define DEFAULT_HOMING_THRESHOLD 2

#define US_PER_SEC 1000000
#define TIMER_FREQ 10000 // ticks per second
#define TIMER_PERIOD (1.0/TIMER_FREQ) // 1ms period
constexpr uint32_t TIMER_COUNT = (48000000 / 8) * TIMER_PERIOD;
#define US_TO_TIMER_COUNT(us) (48000000 / 8) * (us) / 1000000


#define TICKS_PER_US TIMER_FREQ / US_PER_SEC

static_assert(TIMER_COUNT > 0 && TIMER_COUNT < 0xFFFF, "TIMER_COUNT must be greater than 0 and less than 0xFFFF");

#define DOUBLE_BUF_SIZE 1024

#define SENSORLESS_HOMING

enum HomeState
{
    ROUGH,
    BACKUP,
    FINE
};

union MotorError
{
    struct
    {
        bool lostPower : 1;
        bool TMC_lost_comms : 1;
        uint32_t spares : 30;
    } bits;
    uint32_t errors;
};

class MotorStep
{
public:
    MotorStep()
    {
    }
};

class MotorController : public ITask
{
private:
    HardwareSerial &serial_stream;
    easyTMC2209 driver;
    PIDController pid;

public:
    AccelStepper stepper;

    MotorStates controlMode;
    MotorBrake motorBrake;
    String modeString = "";

    //Velocity Step variables
    struct VelocityStep
    {
        PositionMode positionMode;
        int32_t velocity;
        int32_t step;
    };
    std::deque<VelocityStep> velocity_steps;
    long velocity_step_end = 0;

    // data that holds encoder data
    IEncoderInterface *encoder_ptr = nullptr;
    int step = 0;
    bool hold = false;

    // targets and timers
    int target_position = 0;
    int target_velocity = 0;
    uint32_t target_velocity_duration = 0;
    uint32_t target_velocity_timer = 0;

    //    Homing
    bool reached_speed_ = false;
    bool home_state_ = false;
    HomeState home_step = ROUGH;
    int32_t homing_speed_ = DEFAULT_HOMING_SPEED;
    int homing_direction = DEFAULT_HOMING_DIRECTION;
    uint16_t homing_threshold = DEFAULT_HOMING_THRESHOLD;
    float homing_coarse_limit_;
    float homing_fine_limit_;
    


    int error_flag;
    uint32_t state_change_time_;

    uint8_t send_buffer[1024];

    long degreesToSteps(double degrees);
    double stepsToDegrees(long steps);

public:
    MotorController(uint32_t period) : serial_stream(Serial1),
                                       pid(10, 0.01, 0, 100000, 1000),
                                       stepper(stepper.DRIVER, MOTOR_STEP, MOTOR_DIR)
    {
        executionPeriod = period;
        driver = easyTMC2209();
    }

    void OnStart();
    void OnStop();
    void OnRun();
    void OnTimer();

    void SetMotorState(MotorStates state);
    MotorStates GetMotorState();

    void SetMotorBraking(MotorBrake brake);
    MotorBrake GetMotorBraking();

    void SetMaxSpeed(uint32_t spd);
    uint32_t GetMaxSpeed();

    void SetAcceleration(uint32_t acl);
    uint32_t GetAcceleration();

    void SetPosition(double position);
    double GetPosition();

    void SetPositionTarget(double position);
    void SetPositionTargetRelative(double position);
    double GetPositionTarget();

    void SetVelocityTarget(double velocity);
    double GetVelocityTarget();

    void AddVelocityStep(int32_t velocity, int32_t step, uint8_t position_mode);
    void StartPath();

    void setEncoderValueSource(IEncoderInterface *encoder_value);
    uint32_t GetErrors();

    void SetHomeDirection(HomeDirection direction);
    HomeDirection GetHomeDirection();
    
    void SetHomingSpeed(uint32_t speed);
    uint32_t GetHomingSpeed();

    void SetHomeThreshold(uint16_t threshold);
    uint16_t GetHomeThreshold();
    
    bool GetHomeState();
    void Home();
    

    void PrintErrorsToSerial();
};

extern MotorController motorController;

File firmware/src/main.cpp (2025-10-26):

#include <Arduino.h>
#include "wiring_private.h"
#include "Task/Task.h"
#include "MessageProcessor/MessageProcessor.hpp"
#include "LedController/LedController.h"
#include "SerialTextInterface/SerialTextInterface.h"
#include "MotorController/MotorController.h"
#include "EncoderController/EncoderController.h"
#include "DeviceManager/DeviceManager.h"
#include "FlashStorage/FlashStorage.h"
#include "EthernetHAT/AxisEthernet.h"
#include "EthernetHAT/AxisMqtt.h"
#include "AxisMessages.h"
#include <cstdint>
#include <cstdio>
#include "Wire.h"
#include "SPI.h"
#include "DebugPrinter.h"

class StatusLedDriver : public ITask
{
private:
  uint32_t led_timer = 0;
  bool led_state = 0;

public:
  StatusLedDriver(uint32_t period)
  {
    executionPeriod = period;
  }

  void OnStart() override
  {
    pinMode(STAT_LED, OUTPUT);
  }

  void OnStop() override
  {
  }

  void OnRun() override
  {
    digitalWrite(STAT_LED, led_state = !led_state);
  }
};

enum class HATType
{
  NONE,
  ETHERNET,
};

void EvaluateHatType();

TaskManager manager;
MessageProcessor messageProcessor(0);
// external interfaces
SerialTextInterface serialTextInterface(0);

// internal devices
StatusLedDriver statusLight(1000);

DeviceManager deviceManager(0xFFFFFFFF);

void setup()
{
  DEBUG_BEGIN(115200);
  Serial.begin(115200);

  Wire1.begin();
  Wire1.setClock(400000);

  pinMode(USR_INPUT, INPUT);
  addrLedController.Start();
  addrLedController.SetLEDColor(CRGB(0x001100));
  uint32_t start_time = millis();
  while(digitalRead(USR_INPUT) && (millis()-start_time)<1500){delay(10);}
  if (!digitalRead(USR_INPUT))
  {
    while (!Serial)
    {
      addrLedController.Start();
      digitalWrite(STAT_LED, LOW);
      addrLedController.SetLEDColor(CRGB(0x0000F0));
      delay(80);
      digitalWrite(STAT_LED, HIGH);
      addrLedController.SetLEDColor(CRGB(0x000000));
      delay(80);
    }
  }

  FlashStorage::Init();
  addrLedController.SetLEDColor(CRGB(0x000000));

  messageProcessor.AddExternalInterface(&serialTextInterface);
  messageProcessor.AddExternalInterface(&AEthernet);
  messageProcessor.AddExternalInterface(&mqttTask);

  manager.AddTask(&serialTextInterface);
  manager.AddTask(&messageProcessor);
  manager.AddTask(&statusLight);
  manager.AddTask(&addrLedController);
  manager.AddTask(&motorController);
  manager.AddTask(&encoderController);
  //  start the interfaces
  serialTextInterface.Start();

  // start the message processor
  messageProcessor.Start();
  addrLedController.Start();
  addrLedController.SetRainbowBrightness(100);

  statusLight.Start();

  encoderController.Start();
  motorController.Start();
  motorController.setEncoderValueSource(&encoderController);

  EvaluateHatType();
}

void EvaluateHatType()
{
  // check for the the ethernet hat
  AEthernet.Start();

  if (AEthernet.IsPresent())
  {
    addrLedController.AddLedStep(CRGB::Purple, 100);
    addrLedController.AddLedStep(CRGB::Black, 100);
    manager.AddTask(&AEthernet);
    mqttTask.Start();
    manager.AddTask(&mqttTask);
  }
  else
  {
    addrLedController.AddLedStep(CRGB::Red, 100);
    addrLedController.AddLedStep(CRGB::Black, 100);
  }
}
uint32_t loop_count = 0;
uint32_t loop_count_timer = 15000;
void loop()
{
  loop_count++;
  if(millis()-loop_count_timer>1000)
  {
    DEBUG_PRINTF("Loops per second: %d\n", loop_count);
    loop_count_timer=millis();
    loop_count=0;
  }
  manager.RunTasks();
  FlashStorage::Task();
}

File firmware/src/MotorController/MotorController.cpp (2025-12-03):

#include "MotorController.h"
#include "LedController/LedController.h"
float readVUSB()
{
  return (float)analogRead(PIN_VUSB) * (3.3f / 1024.0f) * 2;
}

float readVBUS()
{
  return analogRead(PIN_VBUS) * (24.0f / 553.0f);
}

bool UserButtonPressed()
{
  return !digitalRead(USR_INPUT);
}

long MotorController::degreesToSteps(double degrees)
{
  return (degrees / 360) * 8 * 200;
}

double MotorController::stepsToDegrees(long steps)
{
  return (steps / 8) * 360 / 200;
}

void TC0_Handler()
{
  if (TC0->COUNT16.INTFLAG.bit.OVF)
  {
    motorController.OnTimer();
    TC0->COUNT16.INTFLAG.bit.OVF = 1;
  }
}

void init_timer()
{
  // Enable the TC0 module
  MCLK->APBAMASK.bit.TC0_ = 1;

  // Configure the Generic Clock Generator 0 (GCLK0) for TC0
  GCLK->PCHCTRL[TC0_GCLK_ID].reg = GCLK_PCHCTRL_GEN_GCLK1 | GCLK_PCHCTRL_CHEN;
  while (GCLK->PCHCTRL[TC0_GCLK_ID].bit.CHEN == 0)
    ;

  GCLK->GENCTRL[1].bit.DIV = 0x00;
  while (GCLK->SYNCBUSY.bit.GENCTRL1)
    ;

  GCLK->GENCTRL[1].bit.DIVSEL = 0;
  while (GCLK->SYNCBUSY.bit.GENCTRL1)
    ;

  DEBUG_PRINTF("Prescaler: %d\n", GCLK->GENCTRL[0].bit.DIV);

  // Reset TC0
  TC0->COUNT16.CTRLA.bit.SWRST = 1;
  while (TC0->COUNT16.SYNCBUSY.bit.SWRST)
    ;

  TC0->COUNT16.CTRLA.bit.MODE = TC_CTRLA_MODE_COUNT16;
  TC0->COUNT16.CTRLA.bit.PRESCALER = TC_CTRLA_PRESCALER_DIV8_Val;
  TC0->COUNT16.WAVE.bit.WAVEGEN = TC_WAVE_WAVEGEN_MFRQ_Val;
  while (TC0->COUNT16.SYNCBUSY.bit.ENABLE)
    ;
  // Set the period (TOP value) for the timer
  TC0->COUNT16.CC[0].reg = TIMER_COUNT;
  while (TC0->COUNT16.SYNCBUSY.bit.CC0)
    ;

  // Enable the overflow interrupt
  TC0->COUNT16.INTENSET.bit.OVF = 1;

  // Enable the TC0 interrupt in the NVIC
  NVIC_EnableIRQ(TC0_IRQn);
  NVIC_SetPriority(TC0_IRQn, 1);

  // Enable TC0
  TC0->COUNT16.CTRLA.bit.ENABLE = 1;
  while (TC0->COUNT16.SYNCBUSY.bit.ENABLE)
    ;
}

void SetTimerIntervalUs(unsigned long interval_us)
{
  // Set the timer period (TOP value) for the timer
  TC0->COUNT16.CC[0].reg = US_TO_TIMER_COUNT(interval_us);
  while (TC0->COUNT16.SYNCBUSY.bit.CC0)
    ;
  // DEBUG_PRINTF("Set timer interval to %lu us\n", US_TO_TIMER_COUNT(interval_us));
}

void MotorController::OnStart()
{

  pinMode(MOTOR_EN, OUTPUT);
  pinMode(MOTOR_STEP, OUTPUT);
  pinMode(MOTOR_DIR, OUTPUT);
  pinMode(MOTOR_M0, OUTPUT);
  pinMode(MOTOR_M1, OUTPUT);
  pinMode(MOTOR_SPREAD, OUTPUT);
  pinMode(MOTOR_DIAG, INPUT);

  digitalWrite(MOTOR_M0, LOW);
  digitalWrite(MOTOR_M1, LOW);
  digitalWrite(MOTOR_EN, HIGH);
  digitalWrite(MOTOR_SPREAD, LOW);

  stepper.setEnablePin(MOTOR_EN);
  stepper.setPinsInverted(true, false, true);
  stepper.disableOutputs();
  stepper.setAcceleration(400 * 8);
  stepper.setMaxSpeed(100 * 8);

  driver.setup(serial_stream, 115200, TMC2209base::SerialAddress::SERIAL_ADDRESS_0);

  SetMotorState(MotorStates::OFF);
  state_change_time_ = millis();
  target_position = 0;

  init_timer();

  stepper.enableOutputs();
}

void MotorController::OnStop()
{
  stepper.disableOutputs();
}

void MotorController::OnTimer()
{
  switch (controlMode)
  {
  case MotorStates::OFF:
    break;
  case MotorStates::POSITION:
    stepper.run();
    if (stepper.distanceToGo() == 0)
    {
      // DEBUG_PRINTF("Position reached: %ld\n", stepper.currentPosition());
      SetMotorState(MotorStates::IDLE_ON);
    }
    break;
  case MotorStates::VELOCITY:
    stepper.runSpeed();
    break;
  case MotorStates::VELOCITY_STEP:
  {

    if (stepper.currentPosition() == velocity_step_end)
    {
      if (velocity_steps.size() == 0)
      {
        // DEBUG_PRINTF("Finished velocity step at %ld\n", stepper.currentPosition());
        stepper.setSpeed(0);
        SetMotorState(MotorStates::IDLE_ON);
        addrLedController.AddLedStep(CRGB::Purple, 500);
        addrLedController.AddLedStep(CRGB::Black, 1);
        return;
      }

      // Done stepping, on to the next
      auto this_move = velocity_steps.front();
      // DEBUG_PRINTF("Current End: %ld, current position: %ld new step: %d\n", velocity_step_end, stepper.currentPosition(), this_move.step);
      if (this_move.positionMode == PositionMode::ABSOLUTE)
      {
        velocity_step_end = this_move.step;
      }
      else if (this_move.positionMode == PositionMode::RELATIVE)
      {
        velocity_step_end = stepper.currentPosition() + this_move.step;
      }
      if (stepper.currentPosition() > velocity_step_end)
      {
        stepper.setSpeed(-this_move.velocity);
      }
      else
      {
        stepper.setSpeed(this_move.velocity);
      }
      velocity_steps.pop_front();
    }
    stepper.runSpeed();
    break;
  }
  case MotorStates::HOME:
  {
    float currentVelocityDegPerSec = encoder_ptr->GetVelocityDegreesPerSecond() * homing_direction;
    homing_coarse_limit_ = homing_direction * ((homing_speed_ * 360) / (200 * 8)) * 0.5f;

    switch (home_step)
    {
    case ROUGH:
    {
      if (!reached_speed_ && (abs(currentVelocityDegPerSec) > abs(homing_coarse_limit_) || currentVelocityDegPerSec < -2))
      {
        reached_speed_ = true;
      }

      if ((abs(currentVelocityDegPerSec) > abs(homing_coarse_limit_) || !reached_speed_))
      {
        stepper.setSpeed(homing_direction * homing_speed_);
        stepper.runSpeed();
      }
      else
      {
        stepper.setSpeed(0);
        stepper.move(homing_direction * -50);
        home_step = BACKUP;
      }
      break;
    }
    case BACKUP:
    {
      stepper.run();
      if (stepper.distanceToGo() == 0 && abs(encoder_ptr->GetVelocityDegreesPerSecond()) < 1)
      {
        homing_fine_limit_ = ((abs(encoder_ptr->GetUpdateRate()) / 2) * 360) / (200 * 8) * 0.3f * homing_direction;
        home_step = FINE;
        reached_speed_ = false;
      }
      break;
    }
    case FINE:
    {
      if (abs(currentVelocityDegPerSec) > abs(homing_fine_limit_) && !reached_speed_)
      {
        reached_speed_ = true;
      }

      if (abs(currentVelocityDegPerSec) > abs(homing_fine_limit_) || !reached_speed_)
      {
        stepper.setSpeed(homing_direction * abs(encoder_ptr->GetUpdateRate()) / 2);
        stepper.runSpeed();
      }
      else
      {
        stepper.setSpeed(0);
        SetMotorState(MotorStates::IDLE_ON);
      }
      break;
    }
    }
    break;
  }
  case MotorStates::IDLE_ON:
    break;
  }
  unsigned long new_int = stepper.GetStepIntervalUs();
  if (new_int <= 10 || new_int > 1000000)
  {
    SetTimerIntervalUs(1000);
  }
  else
  {
    SetTimerIntervalUs(new_int);
  }
}

void MotorController::OnRun()
{
  
}
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

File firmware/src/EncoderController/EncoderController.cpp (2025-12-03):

#include "EncoderController.h"
#include "DebugPrinter.h"
float Wrap0to360(float input)
{
    input = fmodf(input, 360.0f);
    if (input < 0)
    {
        input += 360.0f;
    }
    return input;
}

void EncoderController::OnStart()
{
    Wire1.setClock(400000);
    Wire1.begin();
    Wire1.beginTransmission(device_address);
    byte error = Wire1.endTransmission();
    if (error)
    {
        DEBUG_PRINTLN("Failed to find Encoder");

        addrLedController.AddLedStep(CRGB::Red, 100);
        addrLedController.AddLedStep(CRGB::Black, 100);
    }
    else
    {
        DEBUG_PRINTLN("Can communicate with Encoder");

        addrLedController.AddLedStep(0x222200, 100);
        addrLedController.AddLedStep(CRGB::Black, 100);
    }

    Tlv493dMagnetic3DSensor.begin(Wire1);
    Tlv493dMagnetic3DSensor.setAccessMode(Tlv493d::AccessMode_e::MASTERCONTROLLEDMODE);
    Tlv493dMagnetic3DSensor.disableTemp();
    Tlv493dMagnetic3DSensor.updateData();
    home_position_offset = Wrap0to360(degrees(Tlv493dMagnetic3DSensor.getAzimuth()));
}

void EncoderController::OnStop()
{
}

void EncoderController::OnRun()
{
    if (Tlv493dMagnetic3DSensor.getMeasurementDelay() != executionPeriod)
    {
        executionPeriod = Tlv493dMagnetic3DSensor.getMeasurementDelay();
    }

    long m = micros();
    Tlv493d_Error_t err = Tlv493dMagnetic3DSensor.updateData();
    long t = micros();
    // DEBUG_PRINTF("Micros:%lu\n", t-m);
    if (err != Tlv493d_Error_t::TLV493D_NO_ERROR)
    {
        Serial.printf("Encoder Error: %d\n", err);
    }

    raw_shaft_angle = Wrap0to360(degrees(Tlv493dMagnetic3DSensor.getAzimuth()));
    // round to 1 decimal place
    raw_shaft_angle = roundf(raw_shaft_angle * 10.0f) / 10.0f;
    // Serial.printf("%8.5f\n", raw_shaft_angle);
    //  load the sliding window filter
    //  to avoid invalid values at the ends, apply an offset

    {
        float offset = 180 - raw_shaft_angle;
        sliding_window_center += offset;
        raw_shaft_angle += offset;

        if (sliding_window_center - raw_shaft_angle > sliding_window_radius)
        { // center > shaft_angle
            sliding_window_center = raw_shaft_angle + sliding_window_radius;
        }
        else if (raw_shaft_angle - sliding_window_center > sliding_window_radius)
        { // shaft_angle > center
            sliding_window_center = raw_shaft_angle - sliding_window_radius;
        }
        else
        {
            sliding_window_center = sliding_window_alpha * raw_shaft_angle + (1 - sliding_window_alpha) * sliding_window_center;
        }

        sliding_window_center -= offset;
        raw_shaft_angle -= offset;
    }

    // keep track of the full turns
    float delta = sliding_window_center - prev_sliding_window_center;
    if (delta < -180)
    {
        number_full_turns++;
    }

    if (delta > 180)
    {
        number_full_turns--;
    }

    full_shaft_position = Wrap0to360(sliding_window_center) + (360 * number_full_turns) + home_position_offset;
    prev_sliding_window_center = sliding_window_center;

    float vel = (full_shaft_position - last_full_shaft_position) / ((float)(micros() - last_read_time) / 1000000);
    shaft_velocity = vel * velocity_alpha + shaft_velocity * (1 - velocity_alpha);
    // DEBUG_PRINTF("%8.1f %8.1f %8.1f %lu \n", shaft_velocity, full_shaft_position, last_full_shaft_position, micros()-last_read_time);
    //DEBUG_PRINTF("%8.1f %8.1f %8.1f %8.1f %8.1f\n", sliding_window_center, delta, number_full_turns, full_shaft_position, shaft_velocity);

    last_full_shaft_position = full_shaft_position;

    update_rate_ticker++;

    if (millis() - update_rate_timer > update_rate_poll_period)
    {
        update_rate_timer = millis();
        update_rate = (float)update_rate_ticker * (1000 / (float)update_rate_poll_period);
        update_rate_ticker = 0;
    }

    last_read_time = micros();
}

float EncoderController::GetShaftAngle()
{
    return full_shaft_position;
}

float EncoderController::GetVelocityDegreesPerSecond()
{
    return shaft_velocity;
}

float EncoderController::GetPositionDegrees()
{
    return full_shaft_position;
}

float *EncoderController::GetShaftAnglePtr()
{
    return &full_shaft_position;
}

void EncoderController::SetPosition(float position)
{
    home_position_offset += (position - GetShaftAngle());

    // Serial.printf("raw %f, offset %f, home %f \n", GetShaftAngle(), position, home_position_offset);
}

float EncoderController::GetUpdateRate()
{
    return update_rate;
}

EncoderController encoderController(500);

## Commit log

2023-11-18 motor moves, low torque
2023-12-01 compontents placed
    [Axis_Basic.kicad_pcb, Axis_Basic.kicad_sch, input_power.kicad_sch]
2024-02-20 compete samd21 board
    [Axis_Basic.kicad_pcb, Axis_Basic.kicad_sch]
2024-02-25 PCB layout and routing complete
    [Axis_Basic-B_Cu.gbr, Axis_Basic-B_Mask.gbr, Axis_Basic-B_Paste.gbr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]
2024-02-25 move file and add HAT
    [Axis_Basic-B_Cu.gbr, Axis_Basic-B_Mask.gbr, Axis_Basic-B_Paste.gbr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]
2024-03-01 board tweaks and outputs for jlcpcb
    [Axis_Basic-B_Cu.gbr, Axis_Basic-B_Mask.gbr, Axis_Basic-B_Paste.gbr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]
2024-06-12 New rev for base board
    [Axis_Basic.kicad_pcb]
2024-06-19 PCB ordered
    [Axis_Basic-B_Cu.gbr, Axis_Basic-B_Mask.gbr, Axis_Basic-B_Paste.gbr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]
2024-06-22 Add 32Mhz crystal
    [Axis_Basic.kicad_sch]
2024-06-23 PCB V2 draft
    [Axis_Basic.kicad_pcb, Axis_Basic.kicad_sch]
2024-06-26 PCB v2 ordered
2024-07-14 Update files to KiCAD 8.0.3
    [Axis_Basic.kicad_pcb, Axis_Basic.kicad_sch]
2024-07-30 Update for PCB V2 pins
2024-07-30 missed connections
    [Axis_Basic.kicad_pcb, Axis_Basic.kicad_sch]
2024-08-01 Move pins for addressable LED
    [Axis_Basic.kicad_pcb, Axis_Basic.kicad_sch]
2024-08-01 track uf2 bootloader
2024-08-03 cherry pick led driver from branch
2024-08-03 Fix pin mapping to enable addressable led
    [LedController.cpp, main.cpp]
2024-08-04 Copy variant and board defenition for custom pin mappings
2024-08-10 Working encoder and position filtering
2024-08-11 Update SERCOM pins
    [Axis_Basic.kicad_pcb, Axis_Basic.kicad_sch]
2024-08-18 Absoute motor positioning from encoder
2024-08-22 change name to driver
2024-08-23 PCB V1.0.0 Ordered
    [Axis_Basic-B_Cu.gbr, Axis_Basic-B_Mask.gbr, Axis_Basic-B_Paste.gbr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]
2024-08-25 Fix missed connections
    [Axis_Basic.kicad_pcb]
2024-08-26 Consistent motor control setup
2024-09-01 Power error and update for V1.0.0 PCB
    [EncoderController.cpp, EncoderController.h, LedController.cpp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]
2024-09-01 Set LED state implemented
2024-09-07 Correct motor phase naming
    [Axis_Basic.kicad_sch]
2024-10-13 LED and motor examples
2024-10-14 Encoder interface updates
2024-10-19 PCB V1.1.0
    [Axis_Basic-B_Cu.gbr, Axis_Basic-B_Mask.gbr, Axis_Basic-B_Paste.gbr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]
2024-10-23 Fix resistor values
    [Axis_Basic-CuBottom.gbr, Axis_Basic-CuIn1.gbr, Axis_Basic-CuIn2.gbr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]
2024-10-25 Add Get Velocity command
2024-11-09 update I2C pins for V1.1
2024-11-17 EthernetHat ordered
    [Axis_Basic.kicad_pcb, Axis_Basic.kicad_sch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]
2024-11-28 EthernetHat V1.2.0 ordered
    [Ethernet HAT-B_Cu.gbr, Ethernet HAT-B_Mask.gbr, Ethernet HAT-B_Paste.gbr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]
2024-12-11 Ethernet HAT V1.2.0
    [Ethernet HAT-B_Cu.gbr, Ethernet HAT-B_Mask.gbr, Ethernet HAT-B_Paste.gbr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]
2025-01-01 Add option to print flash buffer
2025-01-01 Control of led over byte message
2025-01-01 Byte message controlling LED
2025-01-03 Finish led messages
2025-01-04 Remove message handlers from device code, finish led interface
2025-01-10 Move to single message handler, correct serial interface
    [AxisEthernet.cpp, FlashStorage.cpp, FlashStorage.h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]
2025-01-10 LED test complete
2025-01-11 CHange motor names
2025-01-11 Update flash part number
    [Axis_Basic.kicad_pcb, Axis_Basic.kicad_sch]
2025-01-26 Refactor Led Controller to use a queue
2025-02-05 Remove Prints
2025-03-01 simple gpio timer
2025-03-04 simple timer functionality
2025-03-09 Add step and velocity mode
2025-03-14 Correct velocity step not starting steps correctly
    [AxisEthernet.cpp, MessageProcessor.cpp, MotorController.cpp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]
2025-03-30 Make timer period change for each step
2025-03-31 Sensorless Homing
2025-04-02 Issues with sensorless homing, revert to encoder homing
    [EncoderController.cpp, EncoderController.h, MotorController.cpp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]
2025-05-26 mqtt velocity and position control
2025-10-17 Send ACK for SetI2C/SetEthernet, relocate LED handlers, expand protocol tests, and reorder GetVersion doc
    - MessageProcessor.cpp
    - Ensure ACK responses are sent for SetI2CAddress and SetEthernetAddress commands.
    - Move SetLedColor/GetLedColor cases to a later position in the switch for clearer grouping.
    - Minor comment spacing cleanup.
    - examples/Python/ProtocolTest.py
    - Expand protocol test: add Set/Get I2C and Set/Get Ethernet tests with ACK handling and additional debug output.
    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
2025-10-26 Update protocol IDs and LED sequencing; add parsing, robust tests, and ACK handling
2025-11-14 Add message checksums, fix LED handling, and create web configurator frontend
    [MessageProcessor.cpp]
2025-11-26 Refactor DualMotorGimbal to simplified position controller, remove GUI/velocity code; add GimbalGearingTest; add debug log to SetVelocityAndStepsMessage
2025-11-26 Add connection indicator UI and improve serial connection status handling
    - Wrap "Connect" button in a .connection-controls container and add a .connection-indicator element in index.html
    - Initialize and toggle the indicator element in script.js (set classes on DOMContentLoaded, connecting, connected, disconnected)
    - Add Web Serial API support check with user alert and clearer status messages on failure
    - Log connect button clicks for easier debugging
    - Update readLoop error handling to mark connection lost and update indicator/status
    - Add styling, animations and state styles for .connection-controls and .connection-indicator in style.css
2025-11-26 Remove legacy Messages.h; simplify LED controller and add activity indicators
    - Delete firmware/include/Messages.h (old message/type definitions removed)
    - Simplify AddrLedController::OnRun to use executionPeriod and immediately show queued steps (remove internal millis timing)
    - Minor formatting cleanup for AddLedStep
    - Add LED activity cues:
    - flash green briefly on incoming byte messages (MessageProcessor::HandleByteMsg)
    - flash blue briefly when sending messages (MessageProcessor::SendMsg)
    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
2025-12-01 Add web configurator frontend and improve serial/UI handling; tweak LED activity
    - Add web_configurator frontend (index.html, style.css, README) with retro "AXIS CONTROL TERMINAL" UI, terminal effects, connection indicator, timestamp, and reorganized controls.
    - Add local server launcher and server script (start_server.sh, serve.py) to serve configurator over HTTP.
    - Enhance script.js: start/boot effects, timestamp updates, richer connection state text, robust serial buffer parsing with resync, checksum verification, extensive TX/RX logging, safer message handling, and update form fields from parsed messages.
    - Fix IP byte order handling (ipToString/stringToIp) to match little-endian wire fo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
    [MessageProcessor.cpp, SerialTextInterace.cpp]
2025-12-01 Add disconnect and "poll all settings" to web configurator; implement serial disconnect and pollAllSettings; shorten LED activity pulses on RX/TX
    [MessageProcessor.cpp]
2025-12-03 Replace direct Serial output with DEBUG_PRINT macros in EncoderController and MotorController
    [EncoderController.cpp, MotorController.cpp]
2025-12-03 Add UDP position test and UDP transport support for web configurator
    - Add examples/Python/UDPPositionControlTest.py: new comprehensive UDP-based
    position control test using AxisUDP/AxisProtocol (connection, retries,
    position/relative/absolute tests, LED feedback, save config, interactive run).
    - web_configurator/index.html: add connection type selector (Serial/UDP) and
    shortcut UDP target IP/port inputs.
    - web_configurator/script.js: support UDP mode:
    - show/hide and sync UDP input fields
    - open EventSource /udp/stream to receive UDP packets from server
    - send outgoing UDP payloads via POST /udp/send
    - add base64 <-> Uint8Array helpers and UDP-specific logging/handling
    - upd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
    [UDPPositionControlTest.py]
2025-12-03 Migrate web configurator server from SimpleHTTPRequestHandler to Flask backend
    - Replace custom ThreadingHTTPServer + CustomHTTPRequestHandler with a Flask app
    - Serve static UI files via Flask and add routes:
    - POST /udp/send to send base64 payloads over UDP (with validation and JSON responses)
    - GET /udp/stream as an SSE endpoint for incoming UDP packets
    - Switch SSE client model to per-client queue objects; udp_receiver_loop pushes JSON/base64 payloads to queues
    - Lazily create and bind shared UDP socket and start receiver thread on first send
    - Clean up imports and startup logging; run Flask app in threaded mode
